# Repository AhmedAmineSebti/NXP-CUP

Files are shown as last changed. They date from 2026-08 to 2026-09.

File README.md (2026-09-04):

# NXP Cup Racing Car

## Overview

The car uses an onboard smart camera to detect track lines, a custom PCB centered on a Teensy 4.1 microcontroller to run the real-time control loops, and a set of IR/ToF sensors for start-line detection and obstacle stopping. This README covers the **mechanical design** and **electronic architecture** of the vehicle.

## Mechanical Design

- Chassis and all mechanical supports designed and modeled in **SolidWorks**.
- **Ackermann steering mechanism**: an **MG996R servo** mounted centrally on the front axle drives both front wheels via a linkage (biellette), so the wheels trace concentric circles in a turn — no lateral scrub.
- **Camera mast**: a raised mount holding the Pixy2 camera for a forward, elevated view of the track.
- **HMI mount**: a dedicated 3D-printed support integrating the OLED display and 2 push buttons.
- Front bumper design integrates 4 IR sensors symmetrically plus a centered ToF sensor.
- Parts were 3D printed; most structural parts in PLA.

## Electronic Architecture

### System Layers

The system is organized in three functional layers around the Teensy 4.1:

- **Perception:** Pixy2 camera (line detection), 4× IR sensors (start/finish line), ToF sensor (obstacle distance)
- **Processing:** Teensy 4.1 — runs two parallel PID loops (steering and speed)
- **Actuation:** MG996R servo (steering), DC motor via H-bridge (propulsion)

### Microcontroller — Teensy 4.1

- ARM Cortex-M7 @ 600 MHz, hardware floating-point unit, 1 MB RAM
- Arduino-compatible, multiple SPI/I²C/UART buses, independent PWM timers
- 35.6 × 17.8 mm footprint, 3.3 V logic level (matches all sensors used)

### Human-Machine Interface (HMI)

- 0.96" OLED display — shows live PID gains and system state
- 2 push buttons — mode selection and race start

### Components Summary

| Component | Reference | Role | Interface |
|---|---|---|---|
| Microcontroller | Teensy 4.1 | Central processing | — |
| Camera | Pixy2 v2 | Line detection | SPI |
| IR sensors | TCRT5000 × 4 | Start/finish line | GPIO |
| ToF sensor | VL53L0X | Obstacle stop | I²C |
| Steering servo | MG996R | Wheel steering | PWM |
| Drive motor | Brushed DC motor | Propulsion | PWM + H-bridge |
| Display | 0.96" OLED | Status display | I²C |
| Buttons | Push button × 2 | Mode selection/Race start | GPIO |
| Wheel encoders | Quadrature, 408 CPR | Speed/position feedback | GPIO (interrupt) |
| Power source | 3S LiPo (12.6 V) | Energy source | — |

### Pinout (Teensy 4.1)

| Pin | Peripheral | Signal | Interface |
|---|---|---|---|
| 12 | Pixy2 Camera | SPI RX (MISO) | SPI0 |
| 11 | Pixy2 Camera | SPI TX (MOSI) | SPI0 |
| 13 | Pixy2 Camera | SPI SCK | SPI0 |
| 10 | Pixy2 Camera | SPI CS | SPI0 |
| 18 | VL53L0X / OLED | I²C SDA | I²C0 |
| 19 | VL53L0X / OLED | I²C SCL | I²C0 |
| 17 | MG996R Servo | PWM | PWM |
| 6-7-22-23 | IBTs | PWM (speed) | PWM |
| 14–17 | IR sensors 1–4 | Start line | GPIO (pull-up) |
| 2-3-4-5 | Rotary encoder | CH A/B | GPIO (interrupt) |
| 8 | Mode button | SW | GPIO |
| 9 | Start button | SW | GPIO |

## Photos

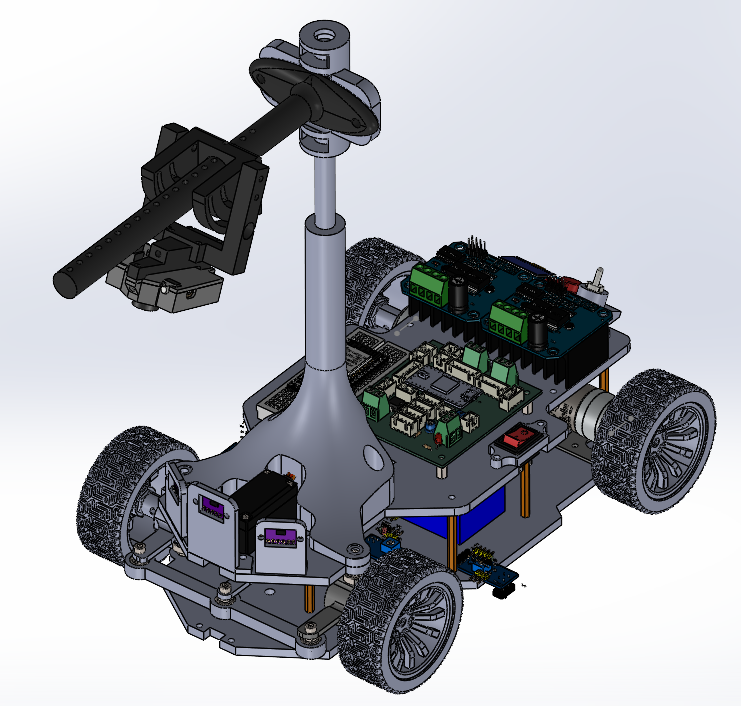
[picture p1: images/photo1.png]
NXP Cup car — isometric view

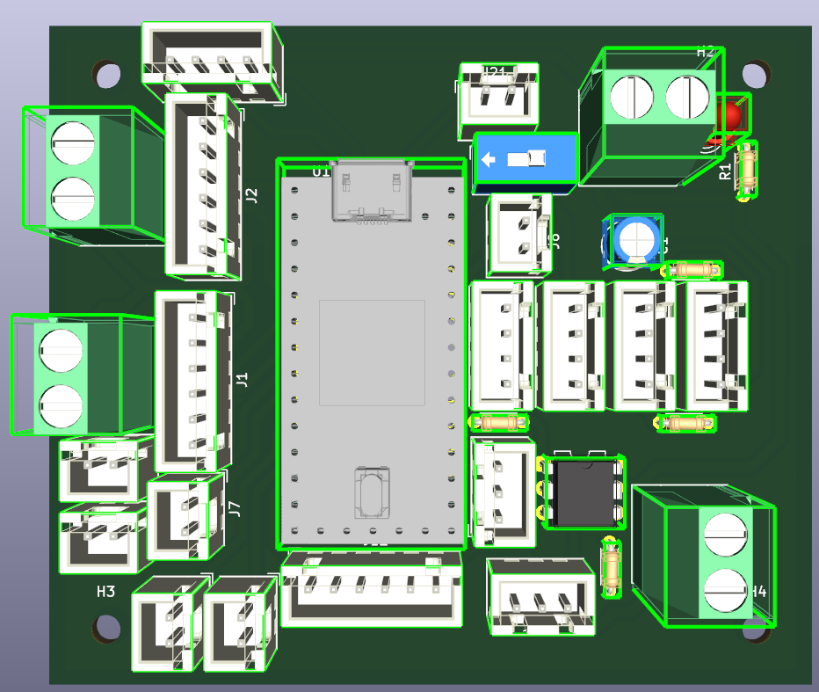
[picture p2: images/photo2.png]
NXP Cup car — front sensors and steering


## Repository Contents

- CAD files (chassis, camera mast, steering mechanism, HMI mount)
- PCB design files (KiCad project)
- 3D-printable part files

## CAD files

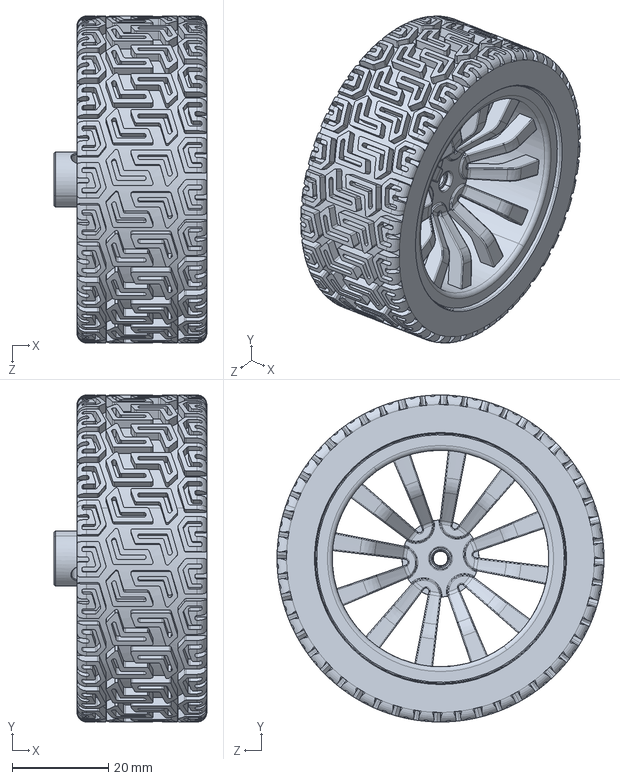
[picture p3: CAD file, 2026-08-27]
mecanique/wheel.SLDPRT
31.8 x 68.0 x 68.0 mm

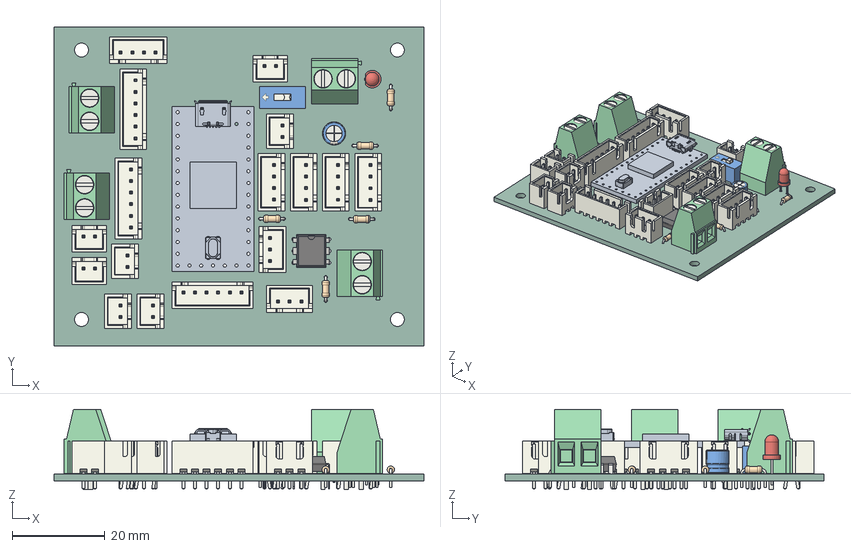
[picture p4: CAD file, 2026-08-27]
éléctronique/shield_teensy4.0/shield_teensy4.0.step
79.6 x 68.8 x 17.3 mm
R_Axial_DIN0204_L3.6mm_D1.6mm_P5.08mm_Horizontal x 5
JST_XH_B2B-XH-A_1x02_P2.50mm_Vertical x 7
TerminalBlock_Phoenix_MKDS-1,5-2_1x02_P5.00mm_Horizontal x 4
JST_XH_B4B-XH-A_1x04_P2.50mm_Vertical x 5
JST_XH_B6B-XH-A_1x06_P2.50mm_Vertical x 3
JST_XH_B3B-XH-A_1x03_P2.50mm_Vertical x 2
LED_D3.0mm
Teensy_4.0_PCB
Micro USB-B Female 5Pin SMD
NXP iMXRT1062
SKRPACE010 v4
DIP-6_W7.62mm
CP_Radial_D5.0mm_P2.50mm
SW_DIP_SPSTx01_Slide_9.78x4.72mm_W7.62mm_P2.54mm
shield_teensy4.0_PCB

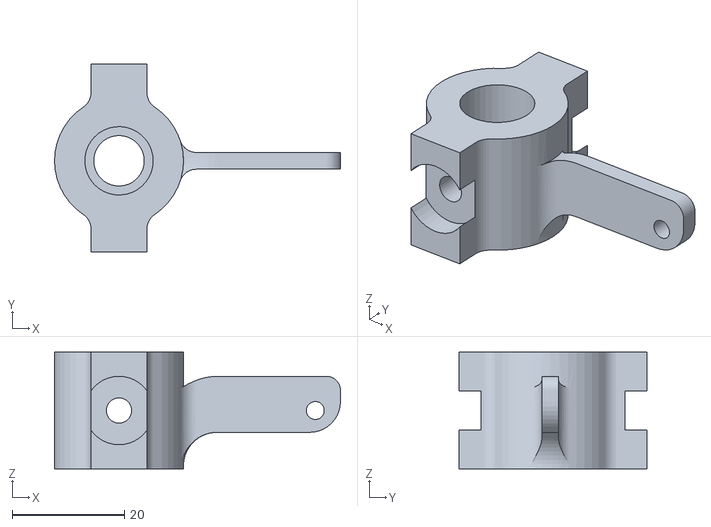
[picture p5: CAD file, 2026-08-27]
mecanique/turner1v2.STL
51.0 x 33.6 x 20.8

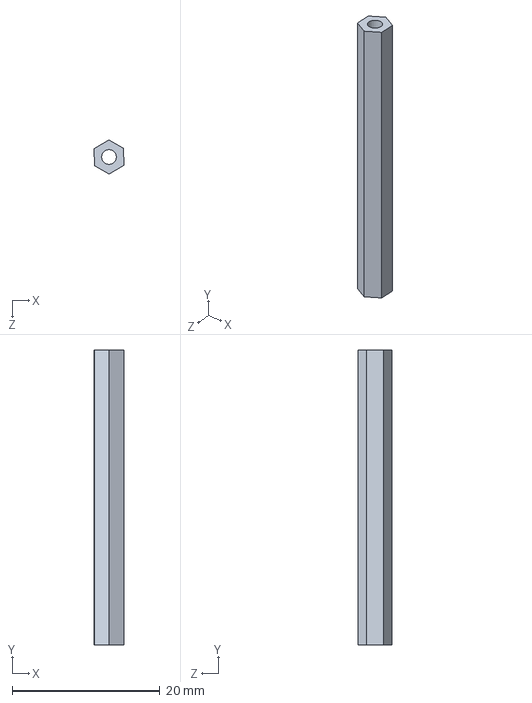
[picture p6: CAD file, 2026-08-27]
mecanique/spacer_45mm.SLDPRT
4.01 x 40.0 x 4.62 mm

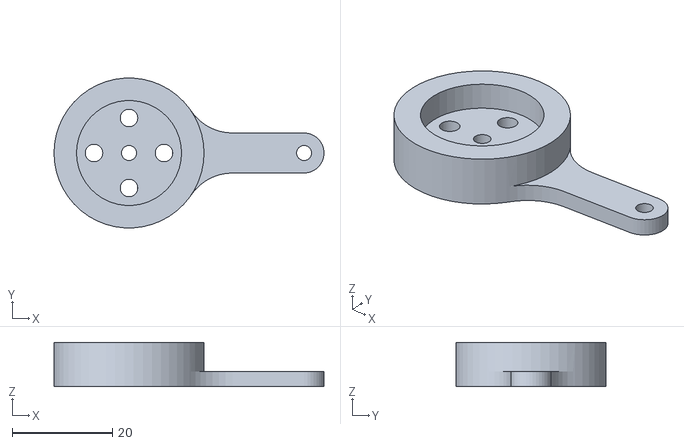
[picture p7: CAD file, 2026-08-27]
mecanique/servohelmetv2.STL
54.0 x 29.9 x 8.80

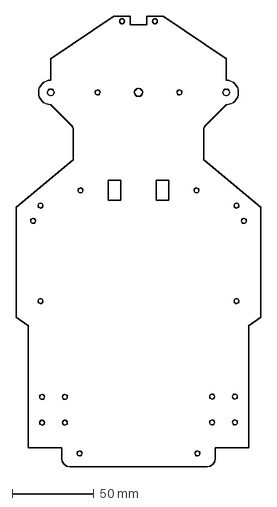
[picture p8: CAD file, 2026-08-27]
mecanique/basemars.DXF
150.0 x 275.8 mm

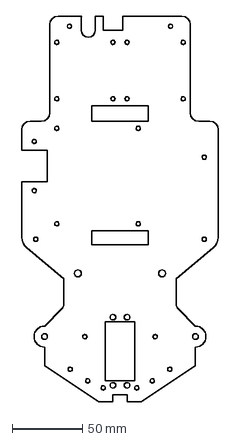
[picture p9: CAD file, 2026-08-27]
mecanique/étage2mars.DXF
140.0 x 275.0 mm

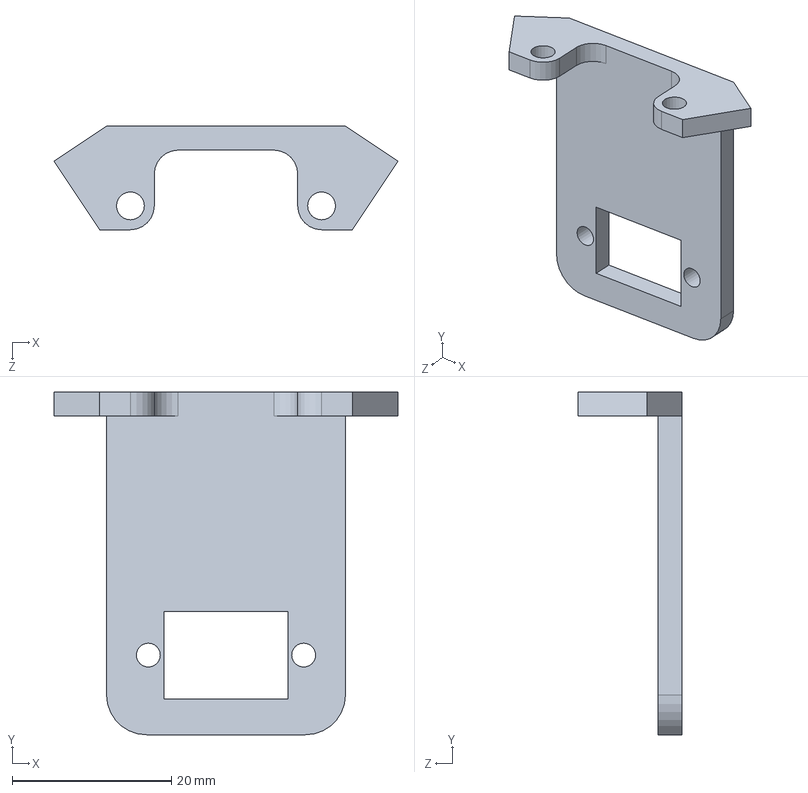
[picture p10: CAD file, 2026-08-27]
mecanique/support_tofwost.SLDPRT
43.2 x 43.0 x 13.0 mm

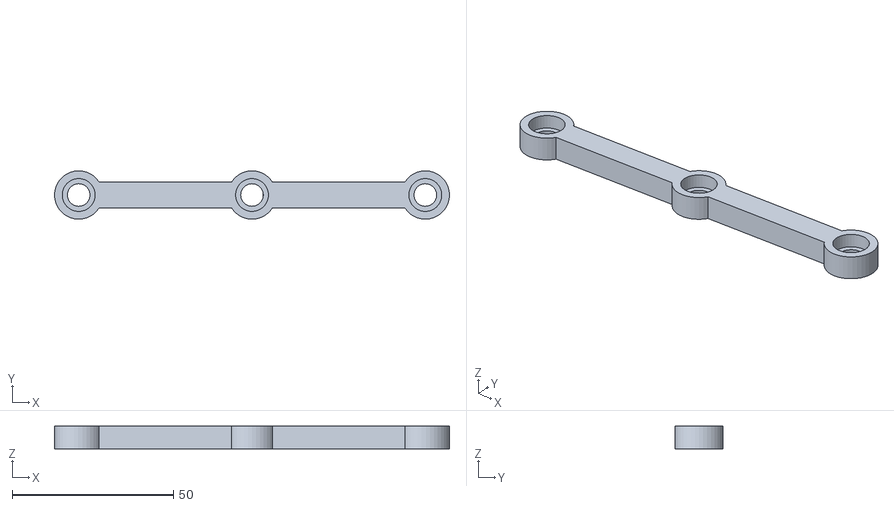
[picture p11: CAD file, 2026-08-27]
mecanique/brasjdidav2.STL
122.5 x 15.0 x 7.00

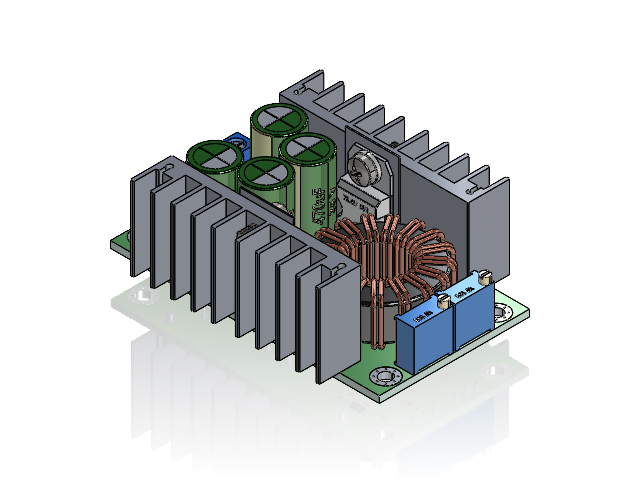
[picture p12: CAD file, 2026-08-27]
mecanique/régulatuer.SLDASM
8A Buck Converter PCB.STEP
Heat Exchanger.STEP x 2
LargeGreen1000uF 35V Electrolytic Capacitor.STEP x 2
LargeGreen470uF 35V Electrolytic Capacitor.STEP x 2
Screw Terminal x2.STEP x 2
TrimmerW103.STEP x 2
whiteLEDShortLeed.STEP
Schottky Diode 20A 45V STPS2045CT.STEP
XL4016E1 8A Voltage Regulator.STEP
Coil for Convertor.STEP
Small Plastic Washer.STEP x 2
pan head cross recess screw_iso_ISO 7045 - M3 x 8 - Z - 8S.STEP x 2
1.7mmSmdCeramicCapacitorbrown.STEP x 8
smdChip8pin.STEP
tinyVoltageRegulator.STEP x 2
TinyVoltageRegulatorAMS1112.STEP
tinySMDResistor222.STEP
tinySMDResistor.STEP x 8
R010 Resistor SMD.STEP
solder.STEP x 28
solder1.8.STEP x 6

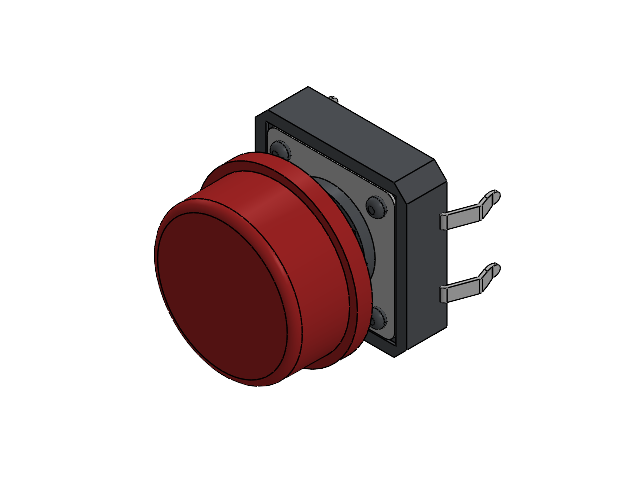
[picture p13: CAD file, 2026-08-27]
mecanique/bouton_12x12mm.SLDASM
base.step
plaque.step
appui.step
pin001.step x 4
Capuchon.step

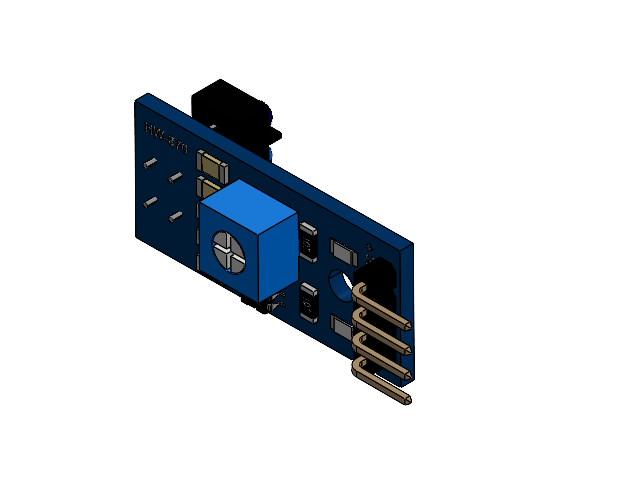
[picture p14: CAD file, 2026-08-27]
mecanique/TCRT5000.SLDASM
AS5600 Geometry.stp
pin.stp
102 Geometry.stp
pin2.stp x 2
103 Geometry.stp x 2
pin3.stp x 3
000 Geometry.stp
pin4.stp
C Geometry.stp x 2
Pin5.stp x 2
4Pin Geometry.stp
PIN6.stp
3Pin Geometry.stp
pin7.stp
Magnet.stp
pot Geometry.stp
leds2 Geometry.stp
pins.stp
Board Geometry.stp
TXT.stp
4PinsOut Geometry.stp
TCRT5000_1.stp

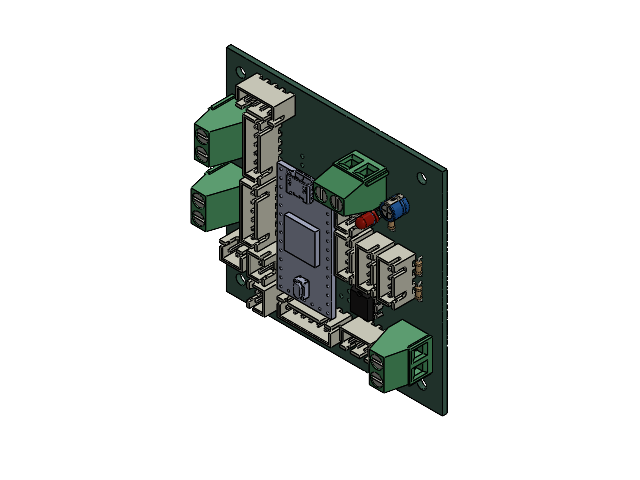
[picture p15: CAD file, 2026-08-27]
mecanique/shield_final.SLDASM
R_Axial_DIN0204_L3.6mm_D1.6mm_P5.08mm_Horizontal.step x 5
JST_XH_B4B-XH-A_1x04_P2.50mm_Vertical.step
JST_XH_B6B-XH-A_1x06_P2.50mm_Vertical.step x 3
TerminalBlock_Phoenix_MKDS-1,5-2_1x02_P5.00mm_Horizontal.step x 3
JST_XH_B3B-XH-A_1x03_P2.50mm_Vertical.step
LED_D3.0mm.step
DIP-6_W7.62mm.step
CP_Radial_D5.0mm_P2.50mm.step
JST_XH_B2B-XH-A_1x02_P2.50mm_Vertical.step x 4
shield_teensy4.0_PCB.step

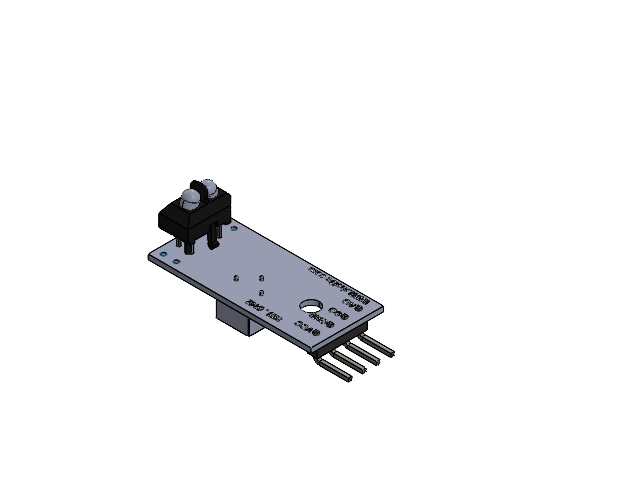
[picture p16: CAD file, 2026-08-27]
mecanique/TCRT5000L Module.SLDASM
Board^TCRT5000L Module(2)_TCRT5000L Module
LEDs^TCRT5000L Module(2)_TCRT5000L Module
Metal Contacts^TCRT5000L Module(2)_TCRT5000L Module
TCRT50003^TCRT5000L Module(2)_TCRT5000L Module
Pin Header^TCRT5000L Module(2)_TCRT5000L Module
3362P-1-102LF-final^TCRT5000L Module(2)_TCRT5000L Module
LM393 IC^TCRT5000L Module(2)_TCRT5000L Module
103 SMD^TCRT5000L Module(2)_TCRT5000L Module x 7
Surface Mount Chip LED 3.2x1.6mm 2^TCRT5000L Module(2)_TCRT5000L Module x 2

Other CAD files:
mecanique/shield_teensy4.0v3.SLDASM
mecanique/shield_teensy4.0v2.SLDASM
mecanique/shield_teensy4.0final.SLDASM
mecanique/shield_teensy4.0.SLDASM
mecanique/25d-metal-gearmotor-4.4-9.7-encoder.SLDPRT
mecanique/3amoud.SLDPRT
mecanique/3amoud.STL
mecanique/3amoud1.STL
mecanique/3amoud2.STL
mecanique/3amoud5.STL
mecanique/BTS7960.SLDPRT
mecanique/Mirrorsupport_tof.SLDPRT
mecanique/RCA.SLDPRT
mecanique/base.DXF
mecanique/base.SLDPRT
mecanique/basecalibrage.DXF
mecanique/basecalibrage.SLDPRT
mecanique/basecalibragefinal.DXF
mecanique/basev2.DXF
mecanique/bras.SLDPRT
mecanique/brasjdida.SLDPRT
mecanique/brasjdida.STL
mecanique/cache_camera.SLDPRT
mecanique/cache_camera.STL
mecanique/camera_holder.SLDPRT
mecanique/camera_holder.STL
mecanique/camera_tilter.SLDPRT
mecanique/camera_tilter.STL
mecanique/dhhar l cache.SLDPRT
mecanique/dhhar l cache.STL
mecanique/jointure.SLDPRT
mecanique/jointure.STL
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

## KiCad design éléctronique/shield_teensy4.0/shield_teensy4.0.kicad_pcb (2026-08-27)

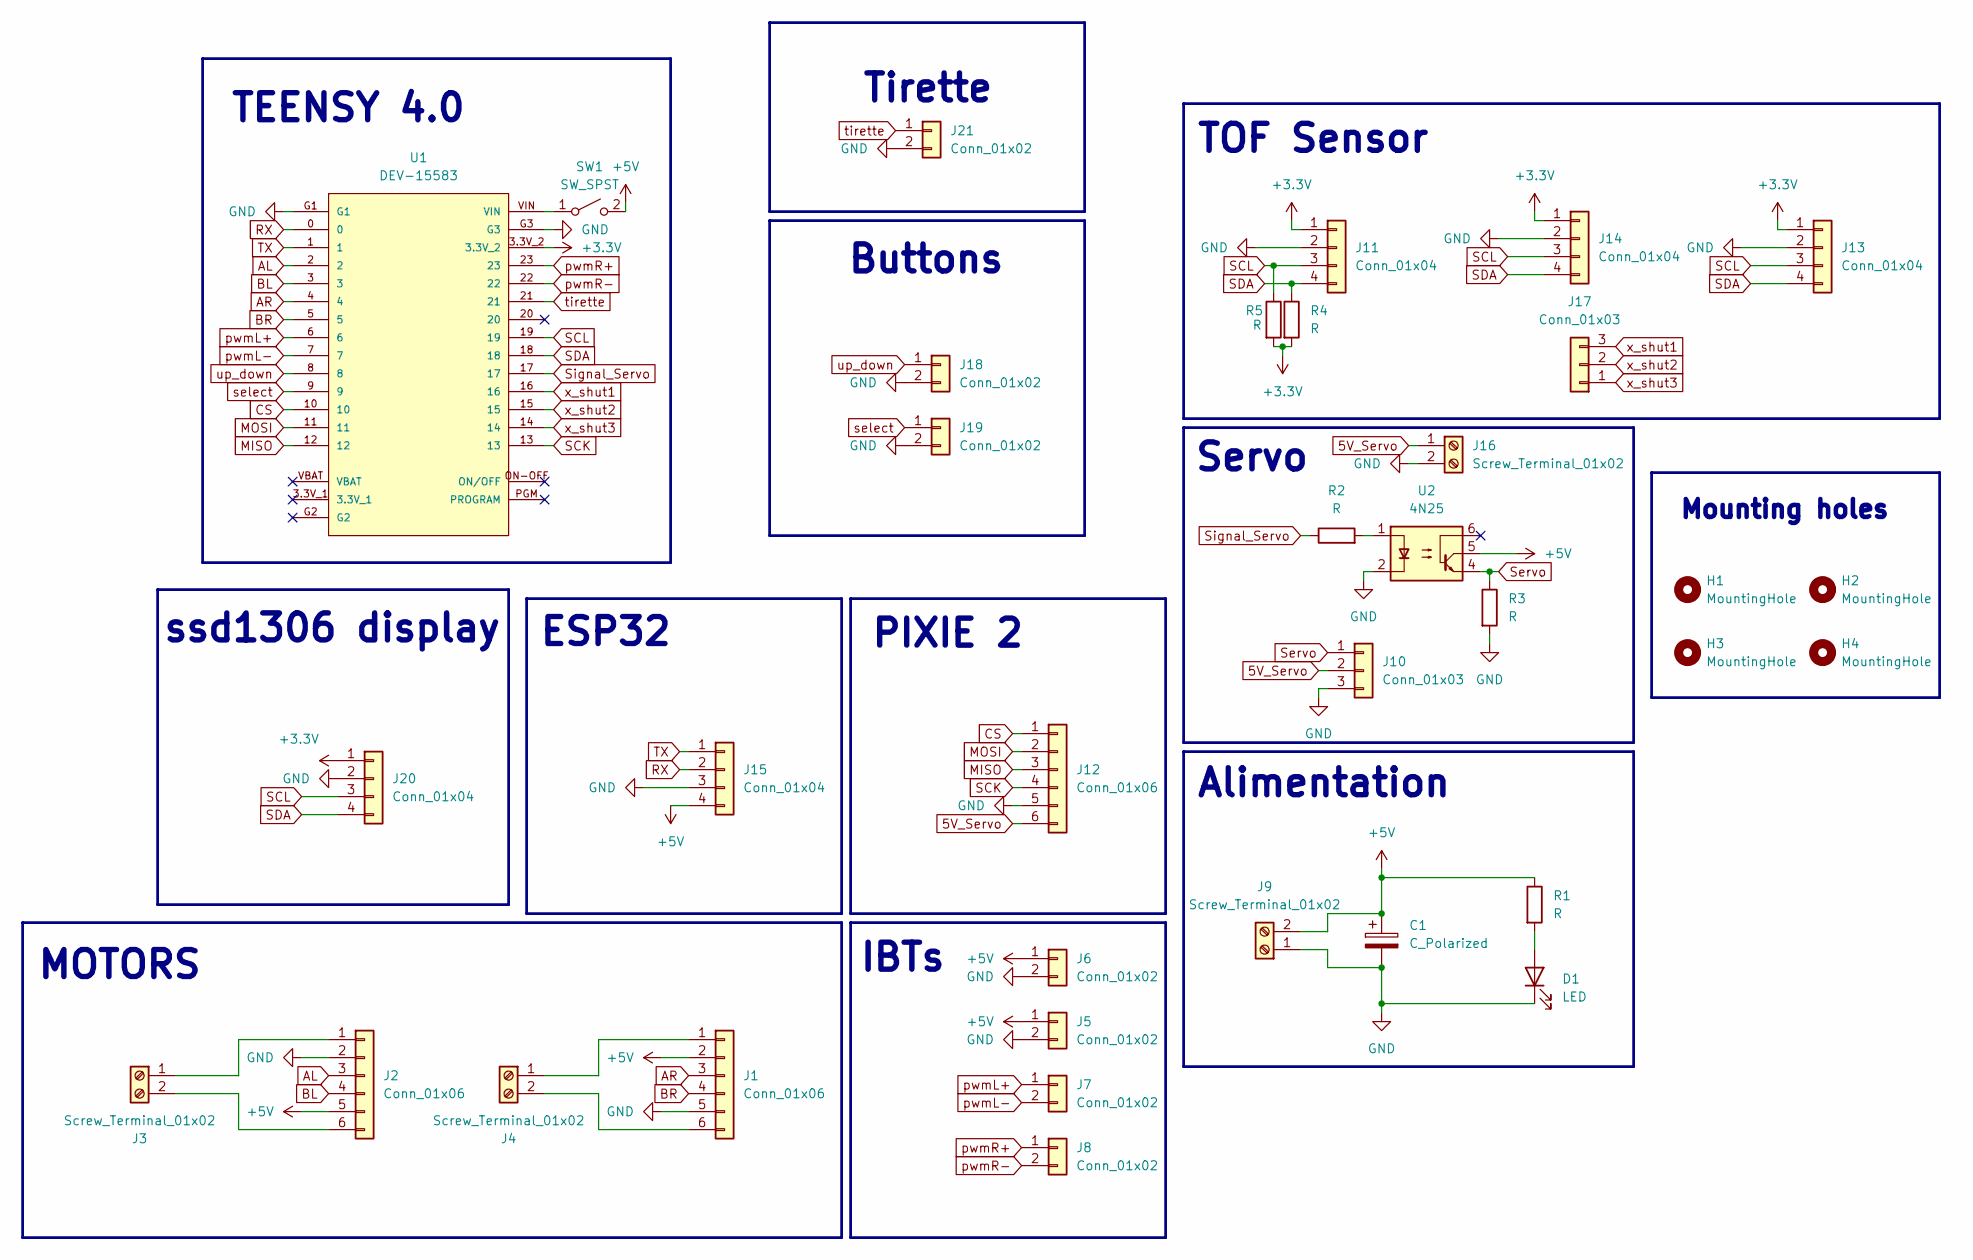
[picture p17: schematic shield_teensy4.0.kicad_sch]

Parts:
C1: C_Polarized; CP_Radial_D5.0mm_P2.50mm
D1: LED; LED_D3.0mm
H1, H2, H3, H4: MountingHole; MountingHole_3mm
J1, J2, J12: Conn_01x06; JST_XH_B6B-XH-A_1x06_P2.50mm_Vertical
J3, J4, J9, J16: Screw_Terminal_01x02; TerminalBlock_Phoenix_MKDS-1,5-2_1x02_P5.00mm_Horizontal
J5, J6, J7, J8, J18, J19, J21: Conn_01x02; JST_XH_B2B-XH-A_1x02_P2.50mm_Vertical
J10, J17: Conn_01x03; JST_XH_B3B-XH-A_1x03_P2.50mm_Vertical
J11, J13, J14, J15, J20: Conn_01x04; JST_XH_B4B-XH-A_1x04_P2.50mm_Vertical
R1, R2, R3, R4, R5: R; R_Axial_DIN0204_L3.6mm_D1.6mm_P5.08mm_Horizontal
SW1: SW_SPST; SW_DIP_SPSTx01_Slide_9.78x4.72mm_W7.62mm_P2.54mm
U1: DEV-15583; MODULE_DEV-15583
U2: 4N25; DIP-6_W7.62mm

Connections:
5V_Servo: J10.2, J12.6, J16.1
+3.3V: J11.1, J13.1, J14.1, J20.1, R4.2, R5.2, U1.3.3V_2
+5V: C1.1, J1.2, J2.5, J5.1, J6.1, J9.2, J15.4, R1.1, SW1.2 (B), U2.5
AL: J2.3, U1.2
AR: J1.3, U1.4
BL: J2.4, U1.3
BR: J1.4, U1.5
CS: J12.1, U1.10
GND: C1.2, D1.1 (K), J1.5, J2.2, J5.2, J6.2, J9.1, J10.3, J11.2, J12.5, J13.2, J14.2, J15.3, J16.2, J18.2, J19.2, J20.2, J21.2, R3.2, U1.G1, U1.G3, U2.2
MISO: J12.3, U1.12
MOSI: J12.2, U1.11
unnamed: D1.2 (A), R1.2
unnamed: J1.1, J4.1
unnamed: J1.6, J4.2
unnamed: J2.1, J3.1
unnamed: J2.6, J3.2
unnamed: R2.2, U2.1
unnamed: SW1.1 (A), U1.VIN
RX: J15.2, U1.0
SCK: J12.4, U1.13
SCL: J11.3, J13.3, J14.3, J20.3, R5.1, U1.19
SDA: J11.4, J13.4, J14.4, J20.4, R4.1, U1.18
Servo: J10.1, R3.1, U2.4
Signal_Servo: R2.1, U1.17
TX: J15.1, U1.1
pwmL+: J7.1, U1.6
pwmL-: J7.2, U1.7
pwmR+: J8.1, U1.23
pwmR-: J8.2, U1.22
select: J19.1, U1.9
tirette: J21.1, U1.21
up_down: J18.1, U1.8
x_shut1: J17.3, U1.16
x_shut2: J17.2, U1.15
x_shut3: J17.1, U1.14

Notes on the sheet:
Buttons
MOTORS
Tirette
IBTs
ssd1306 display
Mounting holes
ESP32
Alimentation
Servo
TEENSY 4.0
PIXIE 2
TOF Sensor

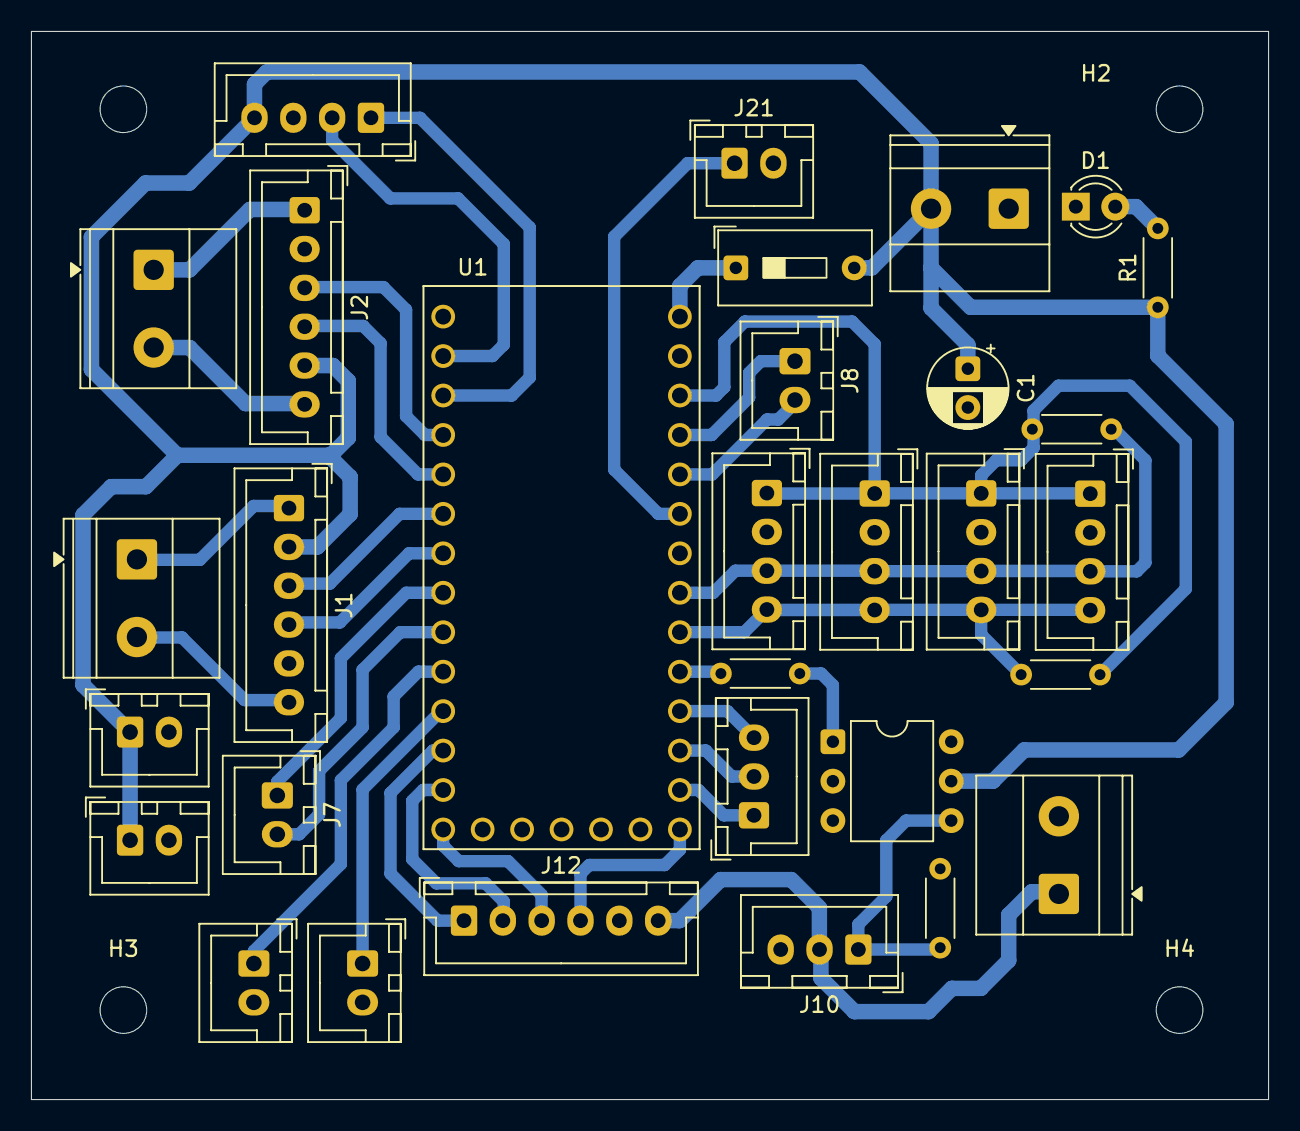
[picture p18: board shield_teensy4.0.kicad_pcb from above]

Board: 2 copper layers, 79.6 x 68.8 mm, 35 parts (0 on the bottom side), 35 nets.

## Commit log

2026-08-27 adding the project files
    [25d-metal-gearmotor-4.4-9.7-encoder.SLDPRT, 3amoud.SLDPRT, 3amoud.STL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]
2026-09-04 Revise HMI mount, power source, and pinout details
    Updated HMI mount description, changed power source voltage, and modified pinout assignments for the Teensy 4.1.
